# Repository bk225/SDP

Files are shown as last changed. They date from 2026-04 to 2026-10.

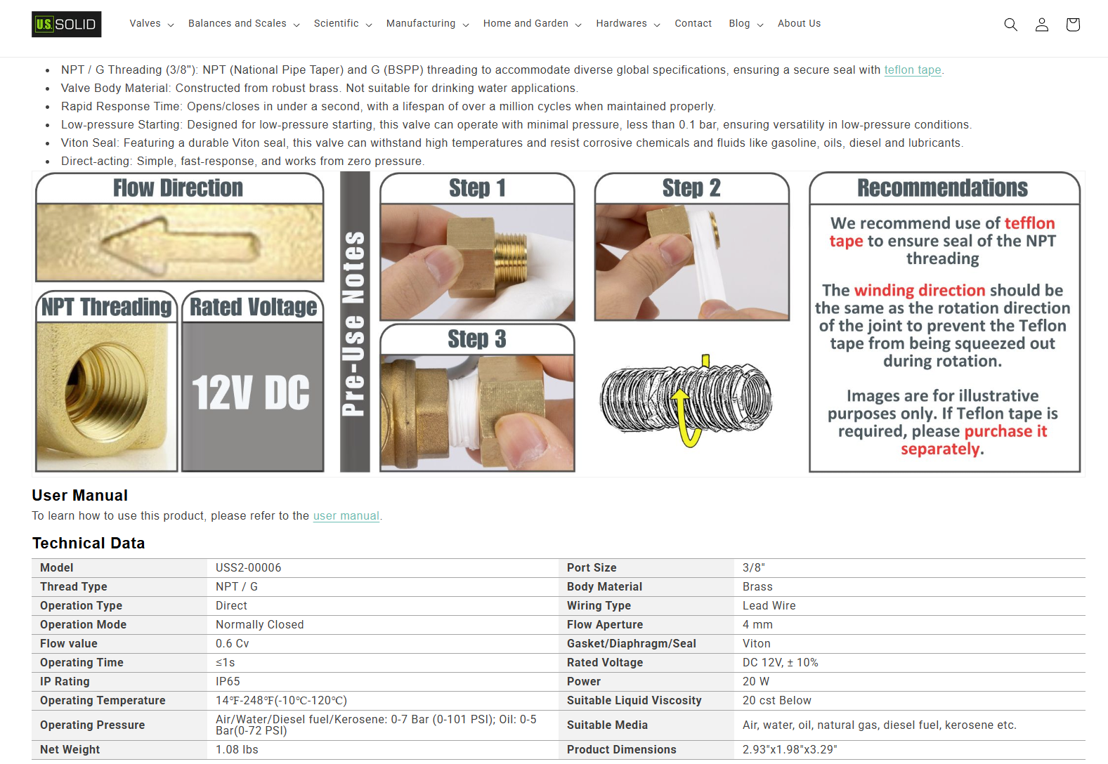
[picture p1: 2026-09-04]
Power_PCB/datasheets/off board/Solenoid Valve/Solenoid Valve Info.png

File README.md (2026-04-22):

# SDP
Overview

This repository contains the electrical system design for an Unmanned Ground Vehicle (UGV) developed for urban firefighting support. The project focuses on designing a reliable, low-noise, and modular electronics architecture to replace a previous prototype that relied on breadboards, long jumper wires, and loosely connected components.

The system includes power distribution, motor control, sensing, and embedded control hardware, with an emphasis on robustness, scalability, and real-world deployment readiness.

Objectives:

Replace unreliable breadboard wiring with a custom PCB-based solution,
Provide stable power rails (24V, 12V, 5V, 3.3V),
Minimize electrical noise from motor drivers affecting logic systems,
Improve grounding and signal integrity,
Support sensor integration for fire detection and navigation.

System Architecture

The UGV electrical system is divided into several subsystems:

Power System: 
  24V input (drive power),
  Buck conversion to 12V, 5V, and 3.3V rails,
  Power distribution to all subsystems,
Control System:
  Microcontroller (STM32 or similar),
  PWM driver (PCA9685) for actuator control,
Actuation:
  BTS7960 motor drivers (external or onboard depending on final design),
  Linear actuator (12V) for steering,
Sensing & Compute:
  Raspberry Pi for high-level processing,
  Sensors: LiDAR, thermal camera, IR, IMU,
  Fire detection sensors (gas, optical, thermal).

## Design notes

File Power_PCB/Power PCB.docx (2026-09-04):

Architecture

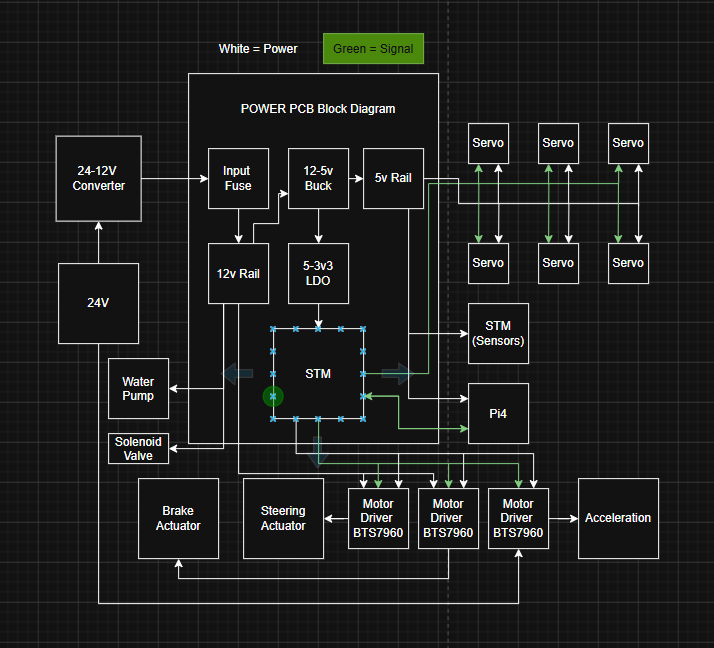
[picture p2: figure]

Parts outside of pcb:

- RasberryPi4 (https://pip-assets.raspberrypi.com/categories/545-raspberry-pi-4-model-b/documents/RP-008341-DS-1-raspberry-pi-4-datasheet.pdf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)
  - Vin – 5.1V
  - 3A nominal
- STM (https://www.st.com/resource/en/user_manual/um2505-stm32g4-nucleo64-boards-mb1367-stmicroelectronics.pdf)
  - Vin - 5V usb-c
- BTS7690 Motor Drivers (3) (https://www.handsontec.com/dataspecs/module/BTS7960%20Motor%20Driver.pdf)
  - Vin 6-27V
  - Control input 3v3 – 5v
  - Peak current 43A
  - Nominal current 10-15A
- 24-12V converter (https://www.ato.com/Content/doc/dc-dc-converter-24v-to-12v/ATOWG-24S1230.pdf)
  - 30A output
- Steering actuator (https://www.pololu.com/product-info-merged/2321)
  - Full load draw - max current draw – 3.2A
  - Vin – 12V
  - No load draw – 1.2A
- Brake actuator (https://images-na.ssl-images-amazon.com/images/I/A12fkCZbVcL.pdf)
  - Vin – 12v
  - Full load current - .24A
  - 10% DC
- Motor (https://electricscooterparts.com/motors-my1016.html)
  - Vin 24v
  - Max/stall current – 30-40A
  - Nominal current - 10A
- Servos
- Water Pump
- Solenoid Valve

Main Parts needed on pcb:

- Input fuse
- 12v - 5v buck
- 5v - 3.3v ldo
- Stm
- Servo motor driver
- Rails for 12v, 5v, 3v3
- 12v-6v dc-dc

NSR020A0X43Z

Part selection:

- Buck Converter
  - MCP16361T-E/NMXVAO (https://www.digikey.com/en/products/detail/microchip-technology/MCP16361T-E-NMXVAO/14291647)
  - LMR51403YFDBVR (https://www.digikey.com/en/products/detail/texas-instruments/LMR51403YFDBVR/25811460)
  - LMR604103SRAKR (https://www.digikey.com/en/products/detail/texas-instruments/LMR604103SRAKR/25891598)
  - BD9G401EFJ-E2 (https://www.digikey.com/en/products/detail/rohm-semiconductor/BD9G401EFJ-E2/25927541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)
  - LMR604605SVBCRQ1
  - TI LMR60440 (https://www.ti.com/lit/ds/symlink/lmr60440-q1.pdf?ts=1777373625343)
    - 4A input
    - Variable output
- Ldo
  - TCR2EF33,LM(CT (https://www.digikey.com/en/products/detail/toshiba-semiconductor-and-storage/TCR2EF33-LM-CT/4503183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)
  - TLV70033DDCR (https://www.digikey.com/en/products/detail/texas-instruments/TLV70033DDCR/2232577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)
    - 200 mA LDO
  - AP2205-W5-7 (https://www.digikey.com/en/products/detail/diodes-incorporated/AP2205-W5-7/10107161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)
- Input fuse
  - Littelfuse MINI-FL1 (https://www.mouser.com/ProductDetail/Littelfuse/178.6764.0001?qs=gu7KAQ731UTQ5alyjBY5mw%3D%3D)
  - KRDB112.5S (https://www.digikey.com/en/products/detail/littelfuse-ibu/KRDB112-5S/7931273)
  - ERDM222 (https://www.digikey.com/en/products/detail/littelfuse-ibu/ERDM222/7941306)
- STM
  - STM32G431KB (https://www.digikey.com/en/products/detail/stmicroelectronics/STM32G431KBT6/10231564?gclsrc=aw.ds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)
    - datasheet (https://datasheet.octopart.com/STM32G431KBT6-STMicroelectronics-datasheet-136120343.pdf)

Current Draws

Component | Nominal | max
Steering actuator | 1.2 | 3.2
Brake actuator | .55 | 1
STM (sensors) | .15 | .3
STM (onboard) | .1 | .2
Pi4 | 2.5 | 3
Servos (6) | 1 | 1.9
Total | 5.5 | 10.1
Motor | 10A | 30-40A

STARTING SCHEMATIC

- MAIN COMPONENTS
  - NSR020A0X43Z
  - TLV70033DDCR (https://www.digikey.com/en/products/detail/texas-instruments/TLV70033DDCR/2232577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)
  - STM32G474CBT6TR
  - LMR51450FSQDRRRQ1
  - 1206L500/12SLPR

LMR51450FSQDRRRQ1

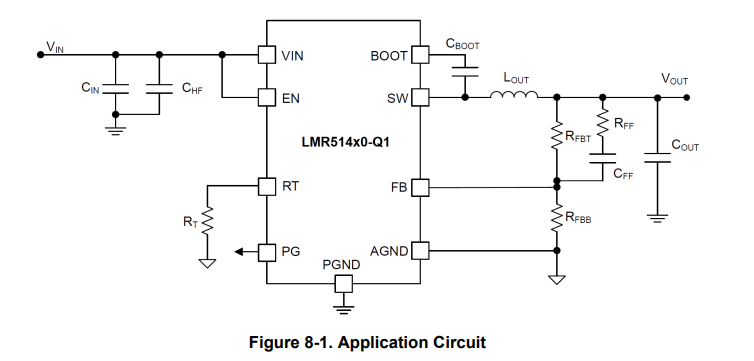
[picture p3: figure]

TLV70033DDCR

Recommends 1u caps for Cin and Cout

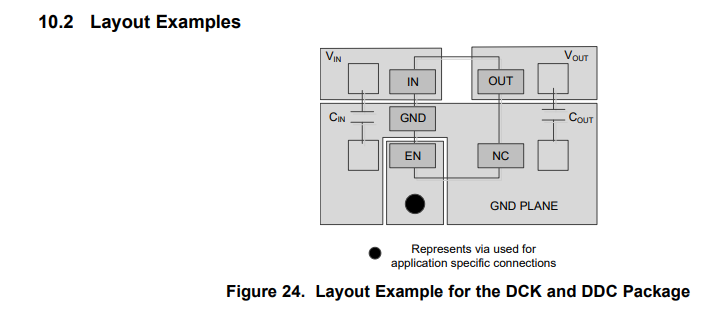
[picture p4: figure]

NSR020A0X43Z

Pin | Name | What it does | For your board
1 | Vout | Regulated output | Connect to 6V_SERVO or 5V_SERVO rail
2 | Trim+ | Output voltage set | One side of trim resistor
3 | GND | Ground | Connect to main GND plane
4 | PwGood | Power-good output | Optional, can go to STM input or leave unused with care
5 | On/Off | Enable pin | Leave open for always-on, or control with STM/MOSFET
6 | Vin | Input voltage | Connect to fused 12V rail
7 | Sense+ | Remote sense positive | Usually connect to Vout / servo rail
8 | Sense- | Remote sense negative | Usually connect to GND
9 | Trim- | Output voltage set reference | Other side of trim resistor
10 | GND | Ground/outrigger | Connect to main GND plane

STM

NEXT STEPS

1. Establish communication between Pi4 and onboard STM
  a. UART between Pi and STM
    i. Pi TX -> STM RX
    ii. Pi RX -> STM TX
    iii. Common GND
2. Establish connection between STM and servos
  a. servo receives:
    i. 5V power
    ii. GND
    iii. PWM signal from STM
3. Establish connection between STM and BTS7960 motor drivers
  a. From STM
    i. PWM
    ii. direction / complementary control
      1. maybe enable
    iii. Shared logic ground
  b. BTS shares gnd with power as well
4. Connectors
  a. Bts7690’s
    i. 8 pins x2
      1. 2 PWM – 3v3
      2. 2 EN – 3v3
      3. VCC – 5v
      4. 2 Gnd
      5. VCC – 12v
    ii. 6 pins
      1. 2 PWM – 3v3
      2. 2 EN – 3v3
      3. VCC – 5v
      4. Gnd
  b. Servos
    i. 3 pins x 6
      1. PWM -3v3
      2. VCC – 5v
      3. Gnd
  c. Pi4
    i. 6 pins
      1. 2 VCC – 5v
      2. 2 Gnd
      3. Tx -3v3
      4. Rx – 3v3
  d. Stm32
    i. 4 pins
      1. 2 VCC
      2. 2 Gnd
  e. 12v connection
    i. 6 pins
      1. 3 VCC
      2. 3 Gnd
  f. Onboard stm
    i. 5 pins
      1. 1 VCC – 3v3
      2. 1 Gnd
      3. 3 Signal
        a. SWDIO
        b. SWCLK
        c. NRST
  g. Solenoid Valve
    i. 2 pins
      1. 1 Gnd
      2. 1 VCC – 12V
  h. Water Pump
    i. 2 pins
      1. 1 Gnd
      2. 1 VCC – 12V

Qty | PCB connector | Use
7 | Molex 0430450612 — Micro-Fit 3.0, 6-position, vertical, through-hole | Pi, onboard STM programming, acceleration BTS7960 logic, 3 servo connectors, offboard STM
2 | Molex 39-28-1063 — Mini-Fit Jr., 6-position, vertical, through-hole | 12 V PCB input, solenoid/pump
2 | Molex 39-28-1083 — Mini-Fit Jr., 8-position, vertical, through-hole | Steering BTS7960, brake BTS7960

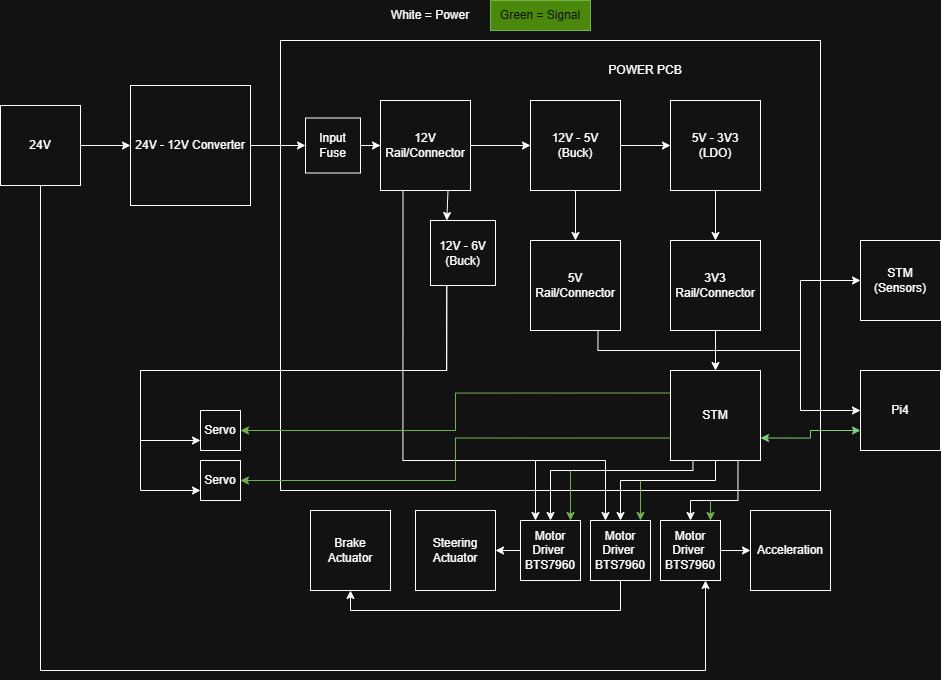
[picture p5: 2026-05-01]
Power_PCB.drawio.png

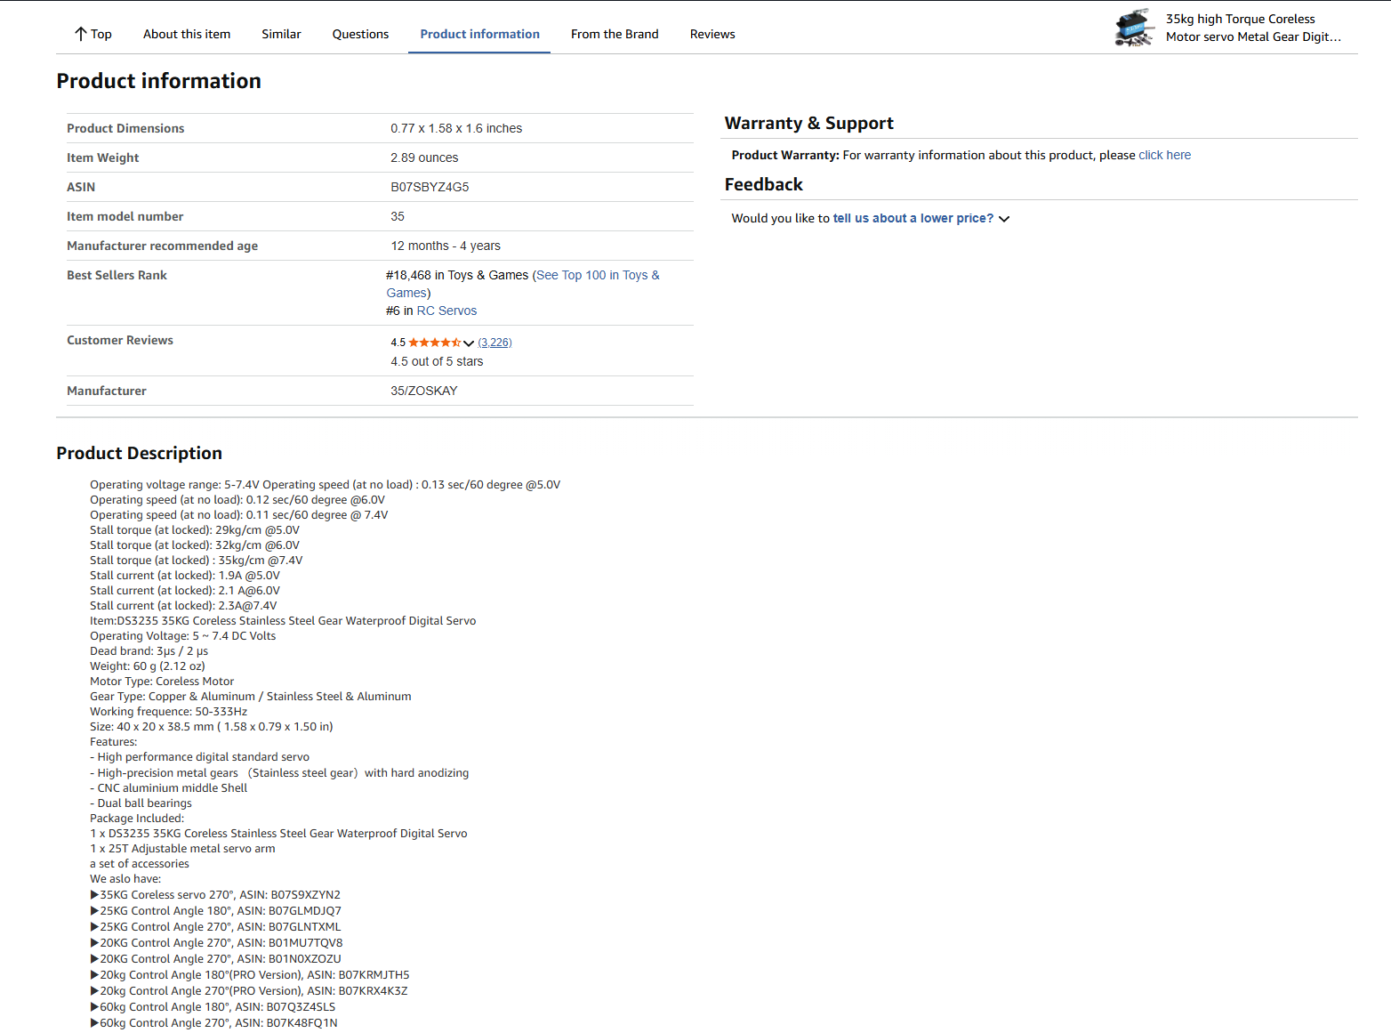
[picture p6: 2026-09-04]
Power_PCB/datasheets/off board/35kg Servos.png

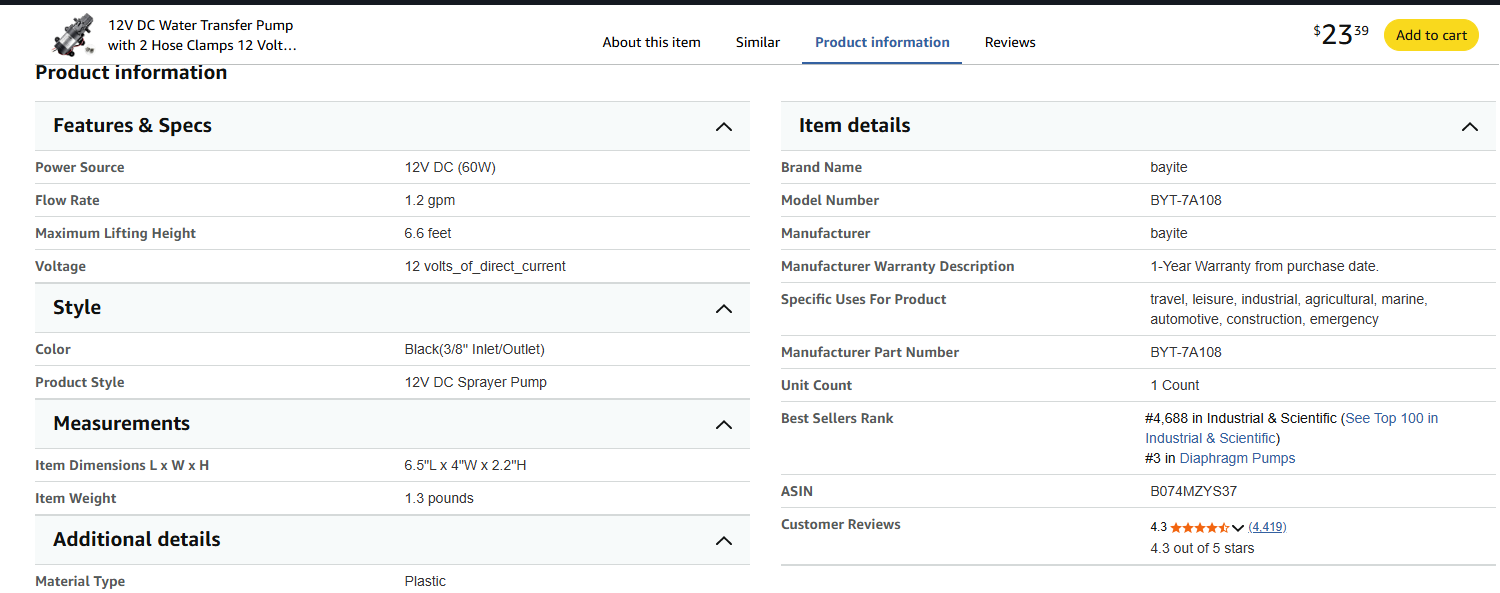
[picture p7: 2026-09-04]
Power_PCB/datasheets/Water Pump Info.png

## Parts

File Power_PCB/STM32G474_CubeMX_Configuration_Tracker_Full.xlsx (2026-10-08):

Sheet: Power & Reset
STM32G474CBT6TR Power, Ground, Reset & Boot Connections
MCU Pin(s) | Net / Rail | Required Connection | Local Components | Placement / Routing | Status | Why / Logic | Source
24, 36, 48 | VDD | Connect all three pins to 3V3 from the TLV70033 rail | 100 nF ceramic from each VDD pin to GND; plus one 4.7-10 uF local bulk capacitor on 3V3 | Each 100 nF should be immediately beside its VDD/VSS pin pair with the shortest possible loop; bulk cap close to MCU | Present - change C19/C21/C22 from 1 uF to 100 nF; C18=10 uF bulk is acceptable | The current schematic has the required three VDD decoupling branches, but the per-pin capacitors are labeled 1 uF. ST specifies one 100 nF ceramic per VDD pin plus one local 4.7 uF bulk capacitor. Keeping 10 uF as the local bulk capacitor is acceptable. | https://www.st.com/resource/en/datasheet/stm32g474re.pdf
23, 35, 47 | VSS | Connect all VSS pins directly to GND | None beyond the VDD decoupling capacitors returning to these ground nodes/plane | Use a continuous low-impedance ground plane; use short vias/traces | Present | All digital ground pins must be connected. A solid ground plane minimizes return impedance and EMI. | https://www.st.com/resource/en/application_note/an5093-getting-started-with-stm32g4-series--hardware-development-boards-stmicroelectronics.pdf
21 | VDDA | Connect VDDA directly to 3V3 (no ferrite bead required for this design) | 10 nF + 1 uF ceramic from VDDA to VSSA | Place both capacitors immediately beside pin 21 with a very short return to VSSA/GND; keep the local analog area away from motor/solenoid switching loops | Present - values correct (C15=1 uF, C16=10 nF) | ST allows the ferrite bead between VDD and VDDA to be replaced by a direct connection. Because this controller is not relying on high-precision analog measurements, direct 3V3 plus the specified local decoupling is the simpler appropriate choice. If later ADC noise testing shows a problem, a bead can be added in a future revision. | https://www.st.com/resource/en/datasheet/stm32g474re.pdf ; https://www.st.com/resource/en/application_note/dm00442716-getting-started-with-stm32g4-series-hardware-development-boards-stmicroelectronics.pdf
19 | VSSA | Connect directly to GND / solid ground plane | Return the VDDA and VREF+ decoupling capacitors to VSSA | Keep the analog decoupling return short; do not leave VSSA floating | Present | VSSA is the analog ground reference. It still must be tied to system ground; leaving it floating would make the analog domain/reference undefined. | https://www.st.com/resource/en/application_note/an5093-getting-started-with-stm32g4-series--hardware-development-boards-stmicroelectronics.pdf
20 | VREF+ | Connect VREF+ directly to VDDA; keep VREFBUF disabled in CubeMX | 100 nF + 1 uF ceramic from VREF+ to VSSA | Place both capacitors immediately beside pin 20 with short return to VSSA/GND | Present - change C14 from 1 uF to 100 nF; keep C13=1 uF | ST shows 100 nF + 1 uF local decoupling on VREF+. The current schematic has two 1 uF capacitors, so one should be changed to 100 nF. | https://www.st.com/resource/en/datasheet/stm32g474re.pdf
1 | VBAT | No backup battery planned: connect VBAT to 3V3/VDD | 100 nF ceramic from VBAT to GND | Place close to pin 1 | Present - C17=100 nF | ST recommends tying VBAT externally to VDD when no battery is used; this keeps the backup domain powered normally and avoids a floating supply pin. | https://www.st.com/resource/en/application_note/an5093-getting-started-with-stm32g4-series--hardware-development-boards-stmicroelectronics.pdf
45 | PB8 / BOOT0 | Add 10 kOhm pull-down from PB8/BOOT0 to GND; optional test pad/jumper to 3V3 if bootloader access is desired | 10 kOhm to GND | Place resistor close to MCU; optional test point can be farther away | Present - R5=10 kOhm pull-down | LOW selects normal boot from user Flash. A hardware pull-down provides a deterministic boot state during reset. SWD remains available for normal programming. | https://www.st.com/resource/en/application_note/an5093-getting-started-with-stm32g4-series--hardware-development-boards-stmicroelectronics.pdf
7 | PG10 / NRST | Route to SWD header; optionally add reset pushbutton from NRST to GND | 100 nF from NRST to GND; no external pull-down | Cap close to MCU; keep reset trace away from noisy motor/solenoid nodes | Present - C20=100 nF and NRST routed to header | NRST is active-low and has an internal pull-up. The capacitor improves reset-noise immunity; the debug tool benefits from access to NRST. | https://www.st.com/resource/en/application_note/an5093-getting-started-with-stm32g4-series--hardware-development-boards-stmicroelectronics.pdf
37, 38, 7 + 3V3/GND | SWD header | Expose SWDIO (PA13), SWCLK (PA14), NRST, 3V3/Vref, and GND | No extra pulls on SWDIO/SWCLK | Keep SWD traces short and accessible; 3V3 on header is target voltage sense, not necessarily programmer power | Present | These five signals are enough for reliable SWD programming/debugging. The MCU provides the normal SWD pulls internally. | https://www.st.com/resource/en/application_note/an5093-getting-started-with-stm32g4-series--hardware-development-boards-stmicroelectronics.pdf
3,4,5,6 | PC14/PC15/PF0/PF1 oscillator pins | Leave unconnected because LSE and HSE are disabled and HSI16 is used | No crystal/load capacitors required | Mark NC/no-connect in schematic if the CAD tool flags them | Confirmed - no external oscillator | The configured clock source is the internal HSI16, so external oscillator components are unnecessary and would only add cost/area. | https://www.st.com/resource/en/application_note/an5093-getting-started-with-stm32g4-series--hardware-development-boards-stmicroelectronics.pdf
34 | PA12 / SOL_GPIO | Keep as GPIO control only; drive a MOSFET/driver input, never the coil directly | 10 kOhm pull-down on control/gate; flyback suppression across the solenoid coil; add gate/base resistor as required by chosen driver | Place flyback device close to coil/connector or power switch current loop; keep high-current return out of MCU ground path | Required hardware around driver | PA12 can source only logic-level current. The solenoid is an inductive load and requires a power switch plus suppression to protect the MCU/driver and reduce EMI. | https://www.st.com/en/microcontrollers-microprocessors/stm32g474cb.html
 | Net naming convention | Use 3V3 as the single net label for VDD1/VDD2/VDD3/VBAT where tied together | Use refdes/text to identify C19->VDD24, C21->VDD36, C22->VDD48, C17->VBAT | Do not create VDD1/VDD2/VDD3/VBAT aliases on the same wire | Confirmed

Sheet: Schematic Review
Final Schematic Review - 2026-09-21
Area / Net | Current schematic | Finding | Required action | Priority | Logic / source
LMR51450 5 V output | 5V label and C8/C9 are connected at the RFF-CFF junction instead of directly to the inductor output node. | This is a real wiring error. The output rail must be the node after L1, which also feeds RFBT and the RFF-CFF branch. | Move the 5V net label and both 33 uF output capacitors to the L1 output node (same node as tops of R1/R2). Leave the R1-C7 midpoint unlabeled/private. | CRITICAL | TI Fig. 9-1 shows COUT and VOUT directly after LOUT. https://www.ti.com/lit/ds/symlink/lmr51450.pdf
5 V rail naming | Buck output is labeled 5V while TLV700 input is labeled 5.1V. | Those are currently different nets in Altium. The feedback divider 100 kOhm / 19.1 kOhm is the TI 5 V design. | Use one net name everywhere, preferably 5V. Rename the TLV700 input/C4/EN rail from 5.1V to 5V. | CRITICAL | TI 5 V design uses 100 kOhm / 19.1 kOhm. https://www.ti.com/lit/ds/symlink/lmr51450.pdf
LMR51450 feedback network | R2=100 kOhm, R3=19.1 kOhm, R1=1 kOhm, C7=33 pF, L1=4.7 uH, C8/C9=33 uF. | Component values match TI 500 kHz / 5 V LMR51450 example once the output node is wired correctly. RT open correctly selects 500 kHz; CBOOT=100 nF is correct. | Keep values; fix only the output-node wiring and place feedback parts close to FB during layout. | OK after wiring fix | TI Table 9-2 and bootstrap guidance. https://www.ti.com/lit/ds/symlink/lmr51450.pdf
LMR51450 input caps | C1/C2=4.7 uF, C3=100 nF on 12 V. | Matches TI example input decoupling. | Keep; use X7R/X5R, 50 V for 4.7 uF parts, and place C3/C1/C2 very close to VIN/PGND. | OK | TI recommends 2x4.7 uF / 50 V + 0.1 uF. https://www.ti.com/lit/ds/symlink/lmr51450.pdf
NSR020A0X43Z trim | R4=220 Ohm between Trim+ and Trim-. | 6.0 V nominal table value is 219 Ohm and the specified set-point accuracy assumes a +/-0.5% trim resistor. | Change R4 to 219 Ohm, preferably 0.5% or 0.1%. | HIGH | OmniOn table lists 219 Ohm for 6.0 V. https://www.mouser.com/datasheet/2/167/nsr020_ds-3402015.pdf
NSR020 output capacitor | C12 currently 470 uF; replacement planned at 220 uF. | Without Tunable Loop the NSR020 permits up to 300 uF external output capacitance for ESR >=1 mOhm. A radial through-hole 220 uF electrolytic is acceptable; SMD is not required. | Use 220 uF, preferably 16 V or 25 V rated, low-ESR radial electrolytic/polymer. Place it close to Vout/GND and observe polarity. Keep total external output capacitance <=300 uF unless Tunable Loop is added. | OK with 220 uF | OmniOn external capacitance limit: 300 uF without Tunable Loop. https://www.mouser.com/datasheet/2/167/nsr020_ds-3402015.pdf
NSR020 input caps | C10/C11=22 uF each at 12 V. | 2x22 uF is directly shown in the datasheet input-ripple guidance. | Keep and place directly adjacent to the Vin/GND pins. Use low-ESR ceramic/polymer with adequate voltage rating. | OK | OmniOn input filtering section uses 2x22 uF or 4x22 uF at 12 V. https://www.mouser.com/datasheet/2/167/nsr020_ds-3402015.pdf
NSR020 sense wiring | Sense+ returns to Vout and Sense- returns to GND locally. | Correct for local sensing. The traces should be Kelvin/sense traces rather than carrying load current. | Keep electrically; route Sense+/- separately to the regulated output/ground point and away from high-current paths. | OK / layout | OmniOn remote sense range is 0.5 V; Kelvin routing avoids load-current drop error. https://www.mouser.com/datasheet/2/167/nsr020_ds-3402015.pdf
TLV70033 | IN and EN tied together; C4=1 uF input, C5=1 uF output; NC open. | Correct always-on configuration. 1 uF input/output capacitors match TI guidance. | Rename input rail to 5V so it is actually connected to the buck. NC may remain open; tying NC to GND is optional for thermal benefit. | OK after net rename | TI TLV700 pin guidance: 1 uF IN and OUT, EN high enables regulator. https://www.ti.com/product/TLV700
MCU VDD decoupling | C19/C21/C22 are each 1 uF; C18 is 10 uF bulk. | Per-VDD capacitors should be 100 nF, not 1 uF. Bulk 10 uF is acceptable. | Change C19, C21, C22 to 100 nF. Keep C18=10 uF (or 4.7 uF). Place one 100 nF at each VDD/VSS pair. | HIGH | ST power scheme: n x 100 nF + 1 x 4.7 uF. https://www.st.com/resource/en/datasheet/stm32g474re.pdf
VDDA | C15=1 uF and C16=10 nF from 3V3/VDDA to GND. | Correct direct-supply decoupling for this design. | Keep; place close to VDDA/VSSA. | OK | ST power scheme shows 10 nF + 1 uF at VDDA. https://www.st.com/resource/en/datasheet/stm32g474re.pdf
VREF+ | C13=1 uF and C14=1 uF. | One capacitor should be 100 nF. | Keep C13=1 uF and change C14 to 100 nF (or vice versa). | HIGH | ST power scheme shows 100 nF + 1 uF at VREF+. https://www.st.com/resource/en/datasheet/stm32g474re.pdf
VBAT / BOOT0 / NRST | VBAT has 100 nF; BOOT0 has 10 kOhm pull-down; NRST has 100 nF and SWD header connection. | These are correct for the current design. | Keep. | OK | STM32G474 datasheet/reset guidance. https://www.st.com/resource/en/datasheet/stm32g474re.pdf
Net aliases | Current drawing uses connector-side names such as ACC_EN1 and MCU-side names such as ACC_EN1_STM even though the only added component is a shunt 10 kOhm pull-down. | A pull-down to GND does not split the signal into two nets; the MCU pin and connector pin are still the same electrical node. Two different net labels on one node are ambiguous and cause Altium warnings. | Use one net name when there is no series element, e.g. ACC_EN1 everywhere. Differentiate MCU-side vs connector-side names only when a series component/buffer/level shifter actually creates two nodes. Use schematic text/comments for visual context if desired. | HIGH / convention | This directly addresses the ERC multiple-name warnings.
3V3 output-to-power ERC | Altium flags U2 OUT driving U4 power pins. | Electrically this is correct: regulator output feeding MCU power pins. The ERC connection matrix is treating Output-to-Power as an error. | Do not change the circuit. In Project Options -> Connection Matrix/Error Reporting, downgrade Output Pin -> Power Pin conflict to Warning/No Report, or use a project-approved power-net/ERC directive. | ERC cleanup | U2 OUT must drive the MCU supply; changing pin types just to silence ERC is less desirable than fixing the ERC rule.
Feedback ERC warning | FB divider net has no driving source. | Expected for a passive divider feeding an analog input; no active output pin exists on that node. | After correcting the 5V output node, place a No ERC directive on the FB warning if it remains. Do not add a fake driver. | ERC cleanup | Passive analog feedback node is valid by design.
Footprint warnings | C18-C22 have no footprints assigned. | BOM/PCB transfer will fail or be incomplete until footprints exist. | Assign footprints to every capacitor/resistor based on the exact selected part. For the new MCU caps, 0603 is a practical default if your assembly process supports it, but the footprint must match the actual manufacturer part. | HIGH | Altium compiler warning shown in current project.
SOL_GPIO | PA12 is routed directly to an external connector; no pull-down is visible on this sheet. | PA12 must not drive a raw solenoid coil. It also benefits from a reset-state pull-down at the driver-control input. | Add 10 kOhm pull-down to SOL_GPIO. Confirm the external device includes a MOSFET/driver and flyback suppression; otherwise add that hardware on this PCB. | CRITICAL if raw coil | MCU GPIO is logic only; inductive loads require a power switch and suppression.
Servo power connectors | Each 6-pin servo header serves two servos with two 6V pins and two GND pins. | Topology is sensible, but each DS3235 can draw about 2.1 A stalled at 6 V. | Verify the exact connector/contact current rating, wire gauge, copper width, and 6V-plane current capability. Two servos on one header can approach ~4.2 A at stall. | HIGH | Load-current path must be rated independently of the logic design.
Input fuse holder | Order includes Littelfuse 178.6764.0001 holder and 0297010.WXNV 10 A MINI 32 V fuse. | The fuse is mechanically/electrically compatible with the holder. Holder rating is 22 A continuous / 30 A max; selected fuse is 10 A fast-acting. Final 10 A sizing still depends on worst-case 12 V system current. | Keep this holder/fuse pairing. Before release, verify total 12 V current including six servos, Pi/5 V rail, solenoid/pump, and any motor power routed through the board; ensure 10 A provides enough operating margin while protecting wiring/PCB. | PART CONFIRMED / sizing pending | Littelfuse holder is rated up to 30 A; protection level comes from the inserted fuse. https://www.littelfuse.com/assetdocs/mini-fl1-datasheet?assetguid=86e3ab08-0473-4acb-98d6-4cf3dbe2f0fa
Micro-Fit 3.0 connectors | Order: Molex 0430450612, 6-position vertical THT; planned for Pi, SWD, accelerator logic, 3 servo connectors, offboard STM. | Correct family/geometry. Molex lists 8.5 A max per contact. Two-servo connectors use separate 6 V and GND contacts per servo, so ~2.1 A stall/contact is comfortably below the header maximum, subject to mating terminal/wire derating. | Keep. Verify mating housing/crimp terminals and wire gauge are also rated appropriately; these mating parts are not present in the uploaded DigiKey order. | OK / mating parts check
Mini-Fit Jr. 6-position | Order: Molex 39-28-1063 / 0039281063, vertical THT; planned for 12 V PCB input and solenoid/pump. | Correct 6-position Mini-Fit Jr. header; Molex lists 9 A max per contact. Parallel contacts on the 12 V input are appropriate if current is shared through equal copper/wiring paths. | Keep. Confirm solenoid/pump worst-case current and mating terminals/wire gauge. | OK / load check
Mini-Fit Jr. 8-position | Order: Molex 39-28-1083 / 0039281083, vertical THT; planned for steering and brake BTS7960. | Correct 8-position Mini-Fit Jr. header; Molex lists 9 A max per contact. If the single 12 V/GND pair on each connector carries actual motor power, 9 A/contact can become the bottleneck even though the BTS7960 itself can handle much more. | Confirm whether these 12 V pins carry motor current or only auxiliary/logic power. If motor current flows here, verify motor stall current and consider paralleling contacts or a higher-current power connector if needed. | HIGH if motor power
24->12 converter / main input | WG-24S1230: 12 V, 30 A, 360 W output; factory output wires are AWG12, 16.5 cm. | Existing 6-pin Mini-Fit Jr. main-input concept relies on parallel contacts and is not the cleanest match to a 30 A-capable source. | Use a dedicated high-current 2-pole connector or direct power termination. Mega-Fit 2-circuit with 12 AWG terminals is a strong fit. Keep Mini-Fit Jr. for the lower-current branch connectors. | HIGH | https://www.molex.com/mega-fit; https://www.ato.com/
Solenoid driver topology | External board: STM32 control -> 220 Ohm gate resistor -> IRLZ44N gate; 10 kOhm gate pulldown; low-side MOSFET; flyback diode across 12 V solenoid. | Topology and diode polarity are correct for a low-side inductive-load switch. | Keep R3=220 Ohm and R4=10 kOhm. Put the gate pulldown physically at the MOSFET. If the main PCB also has a 10 kOhm SOL_GPIO pulldown, the pair becomes 5 kOhm effective and is harmless but redundant. | OK / refine | User-provided external circuit; solenoid is 20 W at 12 V -> 1.67 A.
Solenoid flyback diode | D2 is currently 1N4001. | At switch-off, initial flyback current is approximately the coil current: I = P/V = 20/12 = 1.67 A. 1N4001 is a 1 A average rectifier, so design margin is poor. | Replace D2 with a >=3 A diode. A 5 A / 60 V Schottky such as SB560-E3/54 is a robust through-hole choice. Cathode to +12 V; anode to MOSFET drain/coil low side. | HIGH | https://www.digikey.com/en/products/detail/vishay-general-semiconductor-diodes-division/SB560-E3-54/1023532
Solenoid MOSFET gate drive | Q2 is IRLZ44N driven directly by 3.3 V STM32 GPIO. | IRLZ44N is logic-level, but its guaranteed RDS(on) values are specified at 4 V/5 V/10 V, not 3.3 V. At only 1.67 A it will likely run cool, but 3.3 V conduction is not guaranteed by the RDS(on) table. | Prototype use is reasonable if already built; for a final robust design either verify VDS/temperature at worst case or choose a MOSFET characterized at <=2.5-3.3 V gate drive / use a gate driver. | CHECK | https://www.infineon.com/assets/row/public/documents/24/49/infineon-irlz44n-datasheet-en.pdf
Pump control path | Reconfigured 6-pin connector provides a dedicated 12 V/GND pair for pump plus 12 V/GND/SOL_GPIO for the external solenoid driver. | This is electrically clean if the pump is intended to run whenever that 12 V branch is powered. | If MCU on/off control of the 5 A pump is required, add a separate PUMP_GPIO and a second MOSFET/relay channel sized for >=5 A plus motor transient suppression. The shown IRLZ44N circuit only controls the solenoid. | CONFIRM FUNCTION | User-provided connector + system block diagram.
Main input connector exact parts | Mega-Fit 0768290002/768290002 selected for PCB. | Correct: this is the vertical THT male PCB header. The mating cable side is separate. | Use 1716920202 receptacle housing and 768230343 female 12 AWG crimp terminals. Use 20 A MINI fuse 0297020.WXNV in existing holder. | BUY / UPDATE SCHEMATIC | https://www.molex.com/en-us/products/series-chart/76829; https://www.molex.com/en-us/products/series-chart/171692; https://www.molex.com/en-us/products/series-chart/76823; https://www.digikey.com/en/products/detail/littelfuse-inc/0297020-WXNV/146599
RECOMMENDED | Solenoid/pump/modem 6-pin allocation | The branch now serves three independent 12 V loads: pump, solenoid driver/valve, and modem. | Preferred pinout is three separate 12 V/GND pairs. A single shared ground would carry at least pump 5 A + solenoid 1.67 A + modem current, increasing contact heating and shared-return voltage drop/noise. Move SOL_GPIO elsewhere or change this branch to an 8-position connector and keep SOL_GPIO plus one spare/PUMP_GPIO. | User architecture clarification; Mini-Fit current ratings are per contact and application dependent. | https://www.molex.com/content/dam/molex/molex-dot-com/products/automated/en-us/productspecificationpdf/438/43879/PS-43879-001-001.pdf
KEEP SUPPRESSION | Solenoid flyback protection | The external MOSFET schematic already includes D2 across the solenoid coil. The connector schematic should not show the diode because it is part of the external driver/load circuit, not the connector itself. | Keep a flyback diode or equivalent clamp unless the valve assembly explicitly documents built-in suppression. The valve manual does not document an internal suppression diode. A two-wire valve that is non-polarized should not be assumed to contain a conventional unidirectional flyback diode. | Inductive-current relation V=L*di/dt: interrupting ~1.67 A coil current without a clamp can generate a large drain-voltage spike. | Uploaded U.S. Solid valve manual; user-provided external MOSFET schematic
CONFIRMED | Main-input cart check | Cart shows Molex 0768290002 PCB Mega-Fit header, Molex 1716920202 2-pos receptacle housing, and Littelfuse 0297020.WXNV 20 A MINI fuse. | These are the intended main 12 V PCB connector/housing/fuse parts. Crimp terminals and bulk wire can be purchased later after harness lengths are known. | READY TO ORDER | User cart screenshot
Supply net naming | 3V3 rail is also labeled VBAT, VDD1, VDD2, and VDD3 at points that are physically the same conductor. | These are not separate nets if they are hard-wired together; multiple labels on one wire generate Altium multiple-net-name warnings. | Use 3V3 as the sole net label. Identify each local capacitor by reference/design note instead: C19=U4 VDD pin 24, C21=U4 VDD pin 36, C22=U4 VDD pin 48, C17=VBAT decoupling. | MEDIUM | Net names should represent electrical nodes. Component reference designators and nearby text should identify which supply pin a decoupler belongs to.
Signal net naming around pull-downs | Signals such as ACC_EN1 and ACC_EN1_STM are placed on the same continuous wire with a 10 kOhm pull-down branch to GND. | The pull-down does not create a second signal node; the STM pin, resistor top, and connector pin are one net. | Delete the duplicate *_STM label and use one signal name end-to-end. Use separate *_MCU/_CONN names only if a series element/buffer/isolator actually separates the nodes. | MEDIUM | This clears the multiple-net-name warnings while preserving professional schematic readability.
READABILITY | Sheet organization | Use descriptive sheet/file names and a clear left-to-right functional flow: Power Regulation, Connectors & Interfaces, MCU & Control. | Keep power flowing left-to-right/top-to-bottom and group related circuits with whitespace or section labels. Rename generic files such as schem1.SchDoc to a descriptive name before release. | RECOMMENDED | Schematic documentation practice
READABILITY | Cross-sheet signals | Repeated global net labels work electrically, but can make sheet-to-sheet interfaces harder to follow. | For signals that intentionally cross sheets, consider Altium Ports (or hierarchical sheet entries if you later make the design hierarchical). Keep local net labels for nets that stay on one sheet. | OPTIONAL | Improves traceability without changing circuit function.
READABILITY | Connector documentation | Connector symbols show the physical pin order, but reviewers benefit from immediately seeing destination and function. | Keep physical pin numbers visible; add concise notes such as "To Pi", "To steering BTS7960", or a small pin-function table next to high-value connectors. Keep one signal name per electrical node. | RECOMMENDED | Especially useful for harness build and troubleshooting.
READABILITY | MCU decoupling identification | All VDD/VBAT decouplers share the 3V3 net, so the net name should not be used to identify which capacitor belongs to which MCU pin. | Place each decoupler near the related MCU supply pin on the schematic or add a small note: C19=VDD24, C21=VDD36, C22=VDD48, C17=VBAT. Keep the electrical net name 3V3. | RECOMMENDED | Preserves correct net naming while making intent obvious.
READABILITY | Final documentation cleanup | Zero ERC warnings/errors achieved after net-name cleanup and intentional ERC suppression on analog/power-generation nodes. | Before PCB layout: add No Connect markers to intentionally unused pins, ensure every connector has a unique J designator plus descriptive Comment, fill title blocks, and add short functional labels around the 5V buck, 6V converter, 3V3 LDO, MCU, and connector groups. | RECOMMENDED | Makes the release schematic easier to review and maintain.
READABILITY | Connector annotation | Use the component Designator field J? for every PCB connector/header that has not yet been numbered; use the Comment/Description field for the functional name such as MAIN_12V_IN, PI4, SWD, ACCEL_BTS7960, SERVO_1_2, etc. | Run Altium Tools > Annotation > Annotate Schematics to assign unique J1, J2, ... designators automatically across the project. Do not use descriptive functional names as the designator; keep those as comments/parameters so annotation can safely renumber connectors. | RECOMMENDED | Professional schematic convention: J# identifies the physical connector; the Comment/parameter identifies its purpose.
PACKAGING | Socket / through-hole substitution review | TLV70033DDCR is SOT-23-5, LMR51450FSQDRRRQ1 is 12-pin 3x3 mm WSON, and STM32G474CBT6TR is 48-pin 7x7 mm LQFP; none are PLCC packages. | Do not use PLCC sockets. Specialized SOT-23-5 and LQFP48 test sockets exist, and generic QFN/WSON test sockets exist, but direct soldering is recommended for the final PCB. In particular, keep the LMR51450 directly soldered because its high-current/high-frequency switching loop and exposed thermal/ground pad depend on a low-inductance PCB connection. | RECOMMENDED | If removable prototyping is needed, use a test socket or SMD-to-DIP adapter only on a prototype/daughterboard. Avoid sockets in the vehicle/final assembly because of size, cost, vibration, parasitics, and contact reliability.

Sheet: Connector BOM
Connector / Harness Parts To Buy
Use | Family | Manufacturer Part Number | Location | What it is | Recommended use / wire | Status | Source
Main 12 V PCB header | Molex Mega-Fit | 768290002 / 0768290002 | PCB | 2-position vertical THT male header | 12 AWG main +12 V/GND | YES - replaces 6-pin Mini-Fit main input | https://www.molex.com/en-us/products/series-chart/76829
Main 12 V cable housing | Molex Mega-Fit | 1716920202 | Harness | 2-position TPA-capable receptacle housing | Mate to 768290002 | BUY | https://www.molex.com/en-us/products/series-chart/171692
Main 12 V crimp contact | Molex Mega-Fit | 768230343 / 0768230343 | Harness | Female tin crimp, single 12 AWG (or double 16+16) | 2 per harness + spares | BUY; use with 1716920202 | https://www.molex.com/en-us/products/series-chart/76823
Main 12 V fuse | Littelfuse MINI 297 | 0297020.WXNV | PCB fuse holder | 20 A, 32 V automotive MINI blade fuse | Existing 178.6764.0001 holder | BUY; final rating verify in test | https://www.digikey.com/en/products/detail/littelfuse-inc/0297020-WXNV/146599
Micro-Fit 6-pos mating housing | Molex Micro-Fit 3.0 | 430250600 / 0430250600 | Harness | 6-position dual-row receptacle housing | Pi, SWD, accel logic, 3 servo headers, offboard STM | BUY ~7 + spares | https://www.molex.com/en-us/products/part-detail/430250600
Micro-Fit power crimp | Molex Micro-Fit 3.0 | 430300038 / 0430300038 | Harness | Female tin crimp for 18 AWG, 8.5 A max/contact | Servo power/GND; higher-current 5 V/GND | BUY; match wire OD | https://www.molex.com/en-us/products/part-detail/430300038
Micro-Fit signal crimp | Molex Micro-Fit 3.0 | 430300001 / 0430300001 | Harness | Female tin crimp for 20-24 AWG, 7 A max/contact | PWM, UART, SWD, EN and low-current logic | BUY; 22 AWG is a good default | https://www.molex.com/en-us/products/part-detail/430300001
Mini-Fit Jr. 6-pos mating housing | Molex Mini-Fit Jr. | 39012060 / 39-01-2060 | Harness | 6-position dual-row receptacle housing | Pump + solenoid-driver + modem; 3 dedicated 12V/GND pairs | BUY + spare | https://www.molex.com/en-us/products/part-detail/39012060
Mini-Fit Jr. 8-pos mating housing | Molex Mini-Fit Jr. | 39012080 / 39-01-2080 | Harness | 8-position dual-row receptacle housing | Brake + steering connectors | BUY 2 + spare | https://www.molex.com/en-us/products/part-detail/39012080
Mini-Fit power crimp | Molex Mini-Fit Plus HCS | 457503112 / 0457503112 | Harness | Female tin crimp for 16 AWG, up to 13 A contact rating | Pump 12 V/GND; steering 12 V/GND; other higher-current Mini-Fit pins | BUY; header remains application limit | https://www.molex.com/en-us/products/part-detail/457503112
Mini-Fit signal/light-power crimp | Molex Mini-Fit Jr. | 39-00-0038 | Harness | Female tin crimp for 18-24 AWG, up to 9 A contact rating | PWM/EN/5 V logic; solenoid 12 V/GND at 1.67 A | BUY; 18-22 AWG depending circuit | https://www.newark.com/molex/39-00-0038/contact-18awg-socket-crimp/dp/90B6898
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

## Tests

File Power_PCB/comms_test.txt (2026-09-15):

D13 spi1_sck
d12 SPI1_SDI / EBYTE MISO
d11 SPI1_SDO / EBYTE MOSI
d10 SPI1_CS1 / EBYTE NSS
d9 RST / EBYTE NRST
d8 txen
d7 rxen

#include <SPI.h>

// Elegoo Uno R3 / Arduino Uno pins
const uint8_t PIN_CS    = 10;  // EBYTE NSS
const uint8_t PIN_RST   = 9;   // EBYTE NRST
const uint8_t PIN_TXEN  = 8;   // EBYTE TXEN
const uint8_t PIN_RXEN  = 7;   // EBYTE RXEN

// Uno hardware SPI pins:
// D13 = SCK
// D12 = MISO
// D11 = MOSI

const uint8_t REG_VERSION = 0x42;

uint8_t readRegister(uint8_t reg)
{
  digitalWrite(PIN_CS, LOW);

  // SX1278 SPI:
  // bit 7 = 0 for READ
  SPI.transfer(reg & 0x7F);

  uint8_t value = SPI.transfer(0x00);

  digitalWrite(PIN_CS, HIGH);

  return value;
}

void resetEbyte()
{
  digitalWrite(PIN_RST, LOW);
  delay(10);

  digitalWrite(PIN_RST, HIGH);
  delay(20);
}

void setup()
{
  Serial.begin(115200);

  pinMode(PIN_CS, OUTPUT);
  pinMode(PIN_RST, OUTPUT);
  pinMode(PIN_TXEN, OUTPUT);
  pinMode(PIN_RXEN, OUTPUT);

  // Safe starting states
  digitalWrite(PIN_CS, HIGH);

  // Do not enable TX or RX RF paths yet
  digitalWrite(PIN_TXEN, LOW);
  digitalWrite(PIN_RXEN, LOW);

  SPI.begin();

  // EBYTE manual recommends relatively slow SPI.
  // Start at 1 MHz.
  SPI.beginTransaction(
    SPISettings(1000000, MSBFIRST, SPI_MODE0)
  );

  resetEbyte();

  Serial.println();
  Serial.println("EBYTE E32-400M33S SPI TEST");
  Serial.println("--------------------------");

  uint8_t version = readRegister(REG_VERSION);

  Serial.print("Register 0x42 = 0x");

  if (version < 0x10)
  {
    Serial.print("0");
  }

  Serial.println(version, HEX);

  if (version == 0x12)
  {
    Serial.println("PASS: SX1278 detected.");
  }
  else
  {
    Serial.println("FAIL: Unexpected response.");
  }
}

void loop()
{
  // Nothing yet
}

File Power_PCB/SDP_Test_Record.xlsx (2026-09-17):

SDP Control PCB Verification – Test Record
Record measured results and mark each test as PASS or FAIL after completion.
Test ID | Test Description | Expected Result / Acceptance Criteria | Measured Result | Pass / Fail | Notes
3.3.1 | Breadboard Wiring Inspection | Wiring matches schematic; all grounds connected; no unintended shorts present
3.3.2 | STM32 Development Board Power-Up | STM32 powers normally; 5 V and 3.3 V rails remain within specified limits; no abnormal heating or current draw
3.3.3 | STM32 Digital Output Test | All GPIO outputs switch HIGH and LOW correctly; unrelated outputs remain unchanged
3.3.4 | PWM Output Test | PWM frequency within ±2% of programmed value; duty cycle within ±2 percentage points
3.3.5 | Raspberry Pi–STM32 Communication Test | Reliable UART communication with no corrupted messages, resets, or communication failures
3.3.6 | BTS Motor Driver Interface Test | All three motor-driver channels respond correctly to PWM, enable, direction, and stop commands
3.3.7 | Servo Control Test | Servos move to commanded positions without uncontrolled movement, excessive jitter, or STM32 reset
3.3.8 | Pump and Solenoid Control Test | Pump and solenoid activate only when commanded and turn off correctly without disturbing controller operation
3.3.9 | Integrated Development-System Test | Raspberry Pi, STM32, and connected devices operate together without resets, communication loss, or unintended outputs
4.3.1 | PCB Visual Inspection | No solder bridges, damaged traces, missing parts, incorrect orientations, or poor solder joints
4.3.2 | PCB Continuity / Short-Circuit Test | No power rail has a hard short to ground; required ground and power connections have continuity
4.3.3 | Initial PCB Power-Up | PCB powers normally without entering current limit, excessive current draw, smoke, odor, or abnormal heating
4.3.4 | PCB Power-Rail Verification | 12 V, 5 V, and 3.3 V rails remain within specified voltage limits with acceptable ripple
4.3.5 | Power-Supply Load Test | Regulators maintain correct output voltage under expected operating load without thermal shutdown
4.3.6 | STM32 SWD Programming Test | STM32 is detected, erased, programmed, verified, reset, and operated successfully
4.3.7 | PCB GPIO / Connector Verification | Every connector pin performs its intended schematic function with correct logic levels
4.3.8 | PCB PWM Verification | PWM signals at final connectors meet programmed frequency and duty-cycle requirements
4.3.9 | Raspberry Pi Communication Test | Raspberry Pi communicates reliably with onboard STM32 without corrupted messages or resets
4.3.10 | External Motor Driver Test | All three motor drivers operate independently with correct speed, direction, enable, and stop control
4.3.11 | Servo Test | Each servo responds to its assigned channel and operates without causing supply instability or controller resets
4.3.12 | Pump and Solenoid Test | Both loads operate correctly and independently without communication loss or unintended actuator operation
4.3.13 | Power Transient / Brownout Test | Motor, servo, pump, and solenoid switching does not cause unacceptable rail drop, MCU reset, or communication failure
4.3.14 | Fail-Safe Test | Loss of Raspberry Pi communication or STM32 reset places safety-critical outputs into their defined safe state
4.3.15 | Complete System Functional Test | All system functions operate correctly together without unintended behavior, instability, or excessive heating
4.3.16 | Extended Operational Test | System operates continuously for at least 30 minutes without reset, communication failure, abnormal heating, or voltage instability
Test Summary / Sign-Off
Overall Test Result |  | Tested By |  | Date
PCB Revision |  | Firmware Revision |  | Reviewer / Approver
Comments

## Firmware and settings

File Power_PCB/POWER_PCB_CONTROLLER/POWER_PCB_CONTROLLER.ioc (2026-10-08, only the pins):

Mcu.UserName=STM32G474CBTx
PA0.GPIO_Label=STE_PWM1
PA0.Signal=S_TIM2_CH1
PA1.GPIO_Label=STE_PWM2
PA1.Signal=S_TIM2_CH2
PA10.GPIO_Label=BRA_PWM1
PA10.Signal=S_TIM1_CH3
PA11.GPIO_Label=BRA_PWM2
PA11.Signal=S_TIM1_CH4
PA12.GPIO_Label=Solenoid Valve GPIO
PA12.Signal=GPIO_Output
PA13.Signal=SYS_JTMS-SWDIO
PA14.Signal=SYS_JTCK-SWCLK
PA2.GPIO_Label=SER_PWM5
PA2.Signal=S_TIM5_CH3
PA3.GPIO_Label=SER_PWM6
PA3.Signal=S_TIM5_CH4
PA4.GPIO_Label=ACC_EN1
PA4.Signal=GPIO_Output
PA5.GPIO_Label=ACC_EN2
PA5.Signal=GPIO_Output
PA6.GPIO_Label=SER_PWM1
PA6.Signal=S_TIM3_CH1
PA7.GPIO_Label=SER_PWM2
PA7.Signal=S_TIM3_CH2
PA8.GPIO_Label=ACC_PWM1
PA8.Signal=S_TIM1_CH1
PA9.GPIO_Label=ACC_PWM2
PA9.Signal=S_TIM1_CH2
PB0.GPIO_Label=SER_PWM3
PB0.Signal=S_TIM3_CH3
PB1.GPIO_Label=SER_PWM4
PB1.Signal=S_TIM3_CH4
PB10.GPIO_Label=PI_RX
PB10.Signal=USART3_TX
PB11.GPIO_Label=PI_TX
PB11.Signal=USART3_RX
PB12.GPIO_Label=BRA_EN1
PB12.Signal=GPIO_Output
PB13.GPIO_Label=BRA_EN2
PB13.Signal=GPIO_Output
PB14.GPIO_Label=STE_EN1
PB14.Signal=GPIO_Output
PB15.GPIO_Label=STE_EN2
PB15.Signal=GPIO_Output

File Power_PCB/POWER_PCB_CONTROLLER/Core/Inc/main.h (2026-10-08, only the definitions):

#define STE_PWM1_Pin GPIO_PIN_0
#define STE_PWM1_GPIO_Port GPIOA
#define STE_PWM2_Pin GPIO_PIN_1
#define STE_PWM2_GPIO_Port GPIOA
#define SER_PWM5_Pin GPIO_PIN_2
#define SER_PWM5_GPIO_Port GPIOA
#define SER_PWM6_Pin GPIO_PIN_3
#define SER_PWM6_GPIO_Port GPIOA
#define ACC_EN1_Pin GPIO_PIN_4
#define ACC_EN1_GPIO_Port GPIOA
#define ACC_EN2_Pin GPIO_PIN_5
#define ACC_EN2_GPIO_Port GPIOA
#define SER_PWM1_Pin GPIO_PIN_6
#define SER_PWM1_GPIO_Port GPIOA
#define SER_PWM2_Pin GPIO_PIN_7
#define SER_PWM2_GPIO_Port GPIOA
#define SER_PWM3_Pin GPIO_PIN_0
#define SER_PWM3_GPIO_Port GPIOB
#define SER_PWM4_Pin GPIO_PIN_1
#define SER_PWM4_GPIO_Port GPIOB
#define PI_RX_Pin GPIO_PIN_10
#define PI_RX_GPIO_Port GPIOB
#define PI_TX_Pin GPIO_PIN_11
#define PI_TX_GPIO_Port GPIOB
#define BRA_EN1_Pin GPIO_PIN_12
#define BRA_EN1_GPIO_Port GPIOB
#define BRA_EN2_Pin GPIO_PIN_13
#define BRA_EN2_GPIO_Port GPIOB
#define STE_EN1_Pin GPIO_PIN_14
#define STE_EN1_GPIO_Port GPIOB
#define STE_EN2_Pin GPIO_PIN_15
#define STE_EN2_GPIO_Port GPIOB
#define ACC_PWM1_Pin GPIO_PIN_8
#define ACC_PWM1_GPIO_Port GPIOA
#define ACC_PWM2_Pin GPIO_PIN_9
#define ACC_PWM2_GPIO_Port GPIOA
#define BRA_PWM1_Pin GPIO_PIN_10
#define BRA_PWM1_GPIO_Port GPIOA
#define BRA_PWM2_Pin GPIO_PIN_11
#define BRA_PWM2_GPIO_Port GPIOA
#define Solenoid_Valve_GPIO_Pin GPIO_PIN_12
#define Solenoid_Valve_GPIO_GPIO_Port GPIOA

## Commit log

2026-04-22 pcb block diagram
2026-04-23 initializing schematic/pcb
    [PCB1.PcbDoc, Power_PCB.PrjPcb, schem1.SchDoc]
2026-04-25 Main Components
    main components imported and placed, libraries set up
    [schem1.SchDoc]
2026-05-01 Initial schematic
    buck converters, ldo circuits done + values picked out. need to pick out connectors and figure out stm.
    [schem1.SchDoc]
2026-07-30 Updated schem and libs
    configured connectors, added new dc/dc converter, linked schlib with pcblib.
    [Connectors.SchDoc, Schlib1.SchLib, schem1.SchDoc]
2026-08-11 New parts
    changed stm from 32 pins to 48
    changed buck conv to one with high output amps and in stock
    updated schematic and linked footprints
    [Schlib1.SchLib, schem1.SchDoc]
2026-09-01 Updated footprints
    Missing fuse holder, inductor footprints
    [Connectors.SchDoc, schem1.SchDoc]
2026-09-02 Finished footprints
    [schem1.SchDoc]
2026-09-15 Started configuring stm32 pins
    brake, steering, accel, general config done.
    [Connectors.SchDoc, schem1.SchDoc]
2026-09-17 STM Pins configured
    Need to fix component values and figure out couple more pins
    [Connectors.SchDoc, SDP_Test_Record.xlsx, STM32G474_CubeMX_Configuration_Tracker_Condensed.xlsx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]
2026-09-22 MCU Schem added
    [MCU.SchDoc, schem1.SchDoc]
2026-09-22 Reconfigured headers
    [Connectors.SchDoc, MCU.SchDoc, STM32G474_CubeMX_Configuration_Tracker_Condensed.xlsx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]
2026-09-22 Misc changes
    [MCU.SchDoc, Power_PCB.PrjPcb, Schlib1.SchLib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]
2026-09-22 FINAL SCHEMATIC v1
    cleaned up schematic, added notes
    [Connectors.SchDoc, MCU.SchDoc, PowerRegulation.SchDoc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]
2026-09-22 Initial PCB Layout
    Put all parts in proper location
    [Connectors.SchDoc, MCU.SchDoc, PCB1.PcbDoc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]
2026-09-23 Design rules set + Gnd pour
    [PCB1.PcbDoc]
2026-09-23 Main zones/traces done
    Started mcu signals, 12v, 5v
    [Connectors.SchDoc, PCB1.PcbDoc]
2026-09-26 Pours, traces, vias done
    [PCB1.PcbDoc]
2026-09-26 basic test points added
    12v_in, 12v, 2x gnd, 5v, 3v3
    [PCB1.PcbDoc]
2026-09-28 Final PCB v1
    [PCB1.PcbDoc]
2026-09-29 Misc Changes
    Border, mounting holes, and overlay fixes.
    [PCB1.PcbDoc, Power_PCB.PrjPcb]
2026-09-29 FINAL SCHEMATIC v2
    [MCU.SchDoc]
2026-09-29 Layout Tweaks
    [MCU.SchDoc, PCB1.PcbDoc]
2026-09-29 FINAL PCB v2
    [PCB1.PcbDoc]
2026-09-29 Gerber / Drill files added
    [PCB1.GBL, PCB1.GBO, PCB1.GBP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]
2026-10-08 STM Code generated
    Timer/GPIO code generated and code structure created
    [Power_PCB.PrjPcb, STM32G474_CubeMX_Configuration_Tracker_Full.xlsx]
2026-10-12 started code
    created prototypes for disable/enable motors and motor pwm,
2026-10-14 Footprint fix
2026-10-15 updateMotor,, process packet
    finished updateMotor structure logic, started uart validation
2026-10-21 Stqrted uart validation
2026-10-22 finished uart validation, started motor saftey
2026-10-28 Motor Tests added
2026-10-29 Servo code done
    servo code finished (main.c), motor simulation tests added

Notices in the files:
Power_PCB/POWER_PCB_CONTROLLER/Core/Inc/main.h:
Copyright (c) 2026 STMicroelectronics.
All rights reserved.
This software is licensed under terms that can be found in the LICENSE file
